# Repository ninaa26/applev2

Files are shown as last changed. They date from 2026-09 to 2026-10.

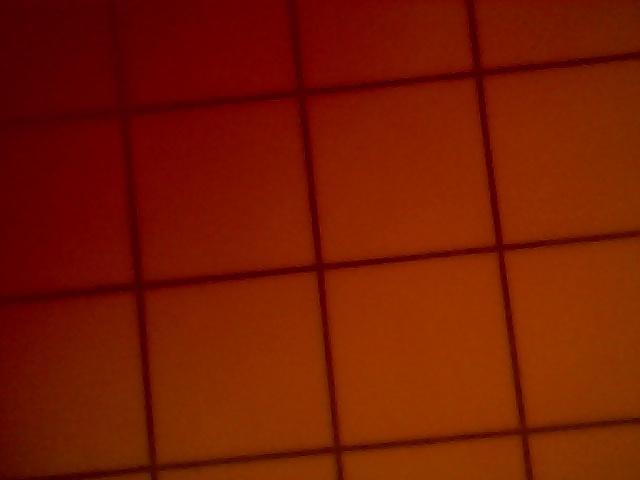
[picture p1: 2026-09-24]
server/tests/fixtures/empty_liner_webcam.jpg

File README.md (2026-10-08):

# Orchard Sentinel

A camera inside a pheromone delta trap that photographs its sticky liner, identifies and counts
codling moth, oriental fruit moth and obliquebanded leafroller, and turns the counts into the
biofix and degree-day timings from the NEWA guide. Cornell capstone, fall 2026.

Planning pages: [spec](https://claude.ai/artifact/GaBWYoqoXfmxyqFotrfH41) ·
[architecture](https://claude.ai/artifact/2WRtPNZk5ZcjBQNcR3oqus) ·
[build plan & tracker](https://claude.ai/artifact/VYyBzxuE8YnGAWV8XVyej5)

```
device/     Raspberry Pi 5 software: wake → LED → photo → queue → upload → set RTC alarm → power off;
            a Pi can also be the hub for ESP32 camera traps (device/esp32-node/ firmware)
server/     FastAPI + SQLite (Postgres later): upload API, detection/tracking/counting worker, dashboard
ml/         training photos (AMI, iNaturalist, trap-style synthetic), labelling tool, detector and classifier training and scoring
hardware/   trap dimensions (TRAP.md), mockup trap template, 3D-printable camera mount + liner tray, calibration prints
docs/       bring-up, wiring, running the server on the Mac, camera bench test, measuring accuracy
```

## Quick start (no hardware needed)

```bash
cd server && uv venv --python 3.12 .venv && uv pip install -p .venv/bin/python -e '.[dev]'
.venv/bin/sentinel-server init && .venv/bin/sentinel-server add-trap T1 --lure CM --name Bench
.venv/bin/sentinel-server serve          # http://localhost:8000
```

Then run the device software with the fake camera ([docs/server-on-mac.md](docs/server-on-mac.md#try-it-without-a-pi)).
With the Pi and camera: [docs/bring-up.md](docs/bring-up.md). More traps on ESP32 camera boards, sending through a hub Pi: [docs/esp32-traps.md](docs/esp32-traps.md). Choosing between cameras: [docs/camera-bench.md](docs/camera-bench.md).

## What works today

- Device cycle: capture with locked focus/exposure/white balance, SHT45 + INA219 readings, offline queue, upload, next-wake scheduling (DST-safe), RTC alarm + power-off, "new liner" by power-button wake; focus-sweep tool. Tested on a Mac with the fake camera. On a Pi so far: capture and white-card calibration with the wide-angle IMX219 on a bench Pi 5 ([hardware/CAMERAS.md](hardware/CAMERAS.md)); **the full cycle has not yet run on the Pi**.
- Server: authenticated uploads (duplicate-safe), new-liner handling, lure masking, detection (OpenCV baseline that measures the liner grid for scale and removes grid lines; corrects wide/fisheye lens distortion by straightening the grid, estimated once per liner; on empty-liner photos, re-run Oct 6 2026: 1 false box on a grid crossing in the Oct 1 webcam photo, and 7 on the IMX219 photo, all on the trap walls outside the card; ignores everything off the card when the lens also sees the trap's walls; leaves out a photo that is blurred or whose scale disagrees with its liner's other photos; folds part-boxes into one box per insect; logs sharpness, glare, liner age and moon with each photo; flatbug adapter; our YOLO11 on overlapping tiles as `SENTINEL_DETECTOR=yolo`), `sentinel-server detect` overlays for bench checks, tracking so each insect counts once (confirmed after 2 photos; species voted only from its first 72 hours on the glue), review queue with confirm/relabel/reject, BE degree days, NEWA sustained-catch biofix, pest milestones, dashboard pages.
- ML ([ml/README.md](ml/README.md)): training set from AMI and iNaturalist, trap-style synthetic photos and, since Oct 7 2026, 2,309 real insects cropped from liner photos (other people's OFM, CM and potato tuber moth liners, and our own field cards with species read from the photos, not yet checked by an entomologist); v1 classifier (BioCLIP 2 features + logistic regression, its settings and confidence scale tuned on real-liner crops): on liners and cards it never trained on it finds 94% of 162 OFM, 92% of 37 CM, 92% of 97 non-target moths, and on held-out field cards 18 of 19 OFM, 10 of 10 CM and 14 of 14 OBLR, at 7–15 px/mm; trained and scored from the `ml/` scripts but not yet switched on in the server (it runs with no species ID); three fine-tuned v2 CNNs (EfficientNet-B0, ConvNeXt-T, MobileNetV3-L; Oct 8 2026, on a CUDA PC) that match v1 on the 785 held-out real-liner crops overall (0.87–0.90 right against 0.89) but find only 3–6 of the 19 OFM on the held-out field card, against v1's 18, and are wrong at ≥ 0.80 3–5 times as often, so v1 stays the classifier; a YOLO11 detector (Oct 8 2026, 31 training photos, the same 4 test photos of other people's liners: mAP50 0.51, moth precision 0.79 and recall 0.74 at its chosen confidence, debris 0 of 13; no better than the Oct 7 run on half the photos), usable in the model playground and as a server detector, not yet tried on a target-size moth from our own camera; a browser labeller for field cards and liner photos; baseline and flatbug detectors scored on other people's labelled liner photos, the classifier scored on field-card crops as moth / other insect / debris.
- ESP32 camera traps ([docs/esp32-traps.md](docs/esp32-traps.md)): a hub Pi takes photos from ESP32-S3 camera boards in Wi-Fi range during each wake and uploads them under each camera's own trap, with each camera's own key. Cameras are added and removed on the dashboard (**Set up traps**), and the hub learns about them from the server. The firmware queues photos in flash, keeps its own time against the hub's and corrects for its clock drift. Tested in code and with a simulated camera through a real gateway on a Mac (Oct 8 2026). Not yet tested: the firmware on real Wi-Fi, and range in an orchard.
- Dashboard: an orchard view (traps reporting, this week's CM/OFM/OBLR across all traps, 30-day chart for the whole orchard) above the per-trap table; each trap's page and a page of all its photos.
- Review: the queue also shows one in ten labels the model was sure of (a spot check, scored on the trap page), and the trap page says when a biofix rests on catches nobody has confirmed.
- Automated tests for device, server and ml, run on every pull request ([.github/workflows/tests.yml](.github/workflows/tests.yml)), plus an end-to-end run: 6 fake-camera cycles → 3 moths detected, 2 confirmed, 1 candidate, which matches the fake camera's ground truth.

## Not done yet

ArUco alignment in the pipeline · white-card calibration for the LED's new position · a diffuser for the LED (10–13% of the card is blown out) · finishing the OFM liner labels (454 boxes) ·
accuracy on our own trap's photos, on locked test cards ([docs/evaluation.md](docs/evaluation.md)) · an entomologist's check of the field-card species and of the 454 pass-1 labels Claude added · a second source of OFM on glue (every CNN learnt the one trap camera's OFM) ·
dashboard settings page for `device_config` · alerts · Postgres/Docker for the real server.

What the insect-monitoring literature says works and fails, and what this repo does about each point, including what could not be done yet: [docs/cv-research-status.md](docs/cv-research-status.md) (imaging, detection, counting) and [docs/ml-research-status.md](docs/ml-research-status.md) (data, classification, evaluation).

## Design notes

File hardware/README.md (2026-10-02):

# Hardware files

The trap is the **Alpha Scents red plastic delta trap** with its 174 × 198 mm insert card (25 mm grid).
Measured dimensions, the schematic and what they mean for the camera: [TRAP.md](TRAP.md).

| File | What it is | Status |
|---|---|---|
| `TRAP.md`, `trap_schematic.svg` | Measured trap and card dimensions, end/side/top schematic | Measured |
| `mockup_template.py` → `mockup_template.svg` | 1:1 cut-and-fold template for a mockup delta trap (roof panels, floor, end flaps, cable slot, LED holes, liner + lure outline), plus a check that the camera sees the whole liner at your dimensions | Works; defaults are the measured Alpha Scents trap |
| `scad/camera_mount.scad` | Wedge that sits in the roof apex and holds the Camera Module 3 Wide facing down | Not yet rendered or printed. **Too low for this trap** (sees ~113 of the card's 174 mm across); needs to become a housing above the peak |
| `scad/liner_tray.scad` | Slide-in tray so every liner lands in the same spot, with pockets for the ArUco markers and a lure seat | Not yet rendered or printed. At the card's size it's wider than the 195 mm floor; shrink the rim/markers first |
| `make_markers.py` → `print/checkerboard.png`, `print/tray_markers.png` | Lens-calibration checkerboard and the four tray-corner ArUco markers (300 dpi) | Works; detection verified with OpenCV |

## Build the mockup

```bash
python mockup_template.py -o mockup_template.svg     # Alpha Scents defaults; --floor-width/--length/--flap/--apex/--liner for another trap
```

1. Print at **100 %** and check the 50 mm scale bar with a ruler.
2. Cut from corrugated plastic (the same material as a real delta trap) or foam board. Score the green dashed lines and fold.
3. Open the `.scad` files in OpenSCAD (free), set `floor_w`/`apex` (mount) and `liner_w`/`liner_l` (tray) to your numbers, press F6, and export STL.
4. Print the markers at 100 %, cut them out, and glue them into the tray pockets: id 0 top-left, 1 top-right, 2 bottom-right, 3 bottom-left, with the camera cable end at the top.
5. After changing the camera height, re-run `mockup_template.py` with the new `--cam-drop` to confirm the liner is still fully in view.

Wiring for the whole unit is in [../docs/wiring.md](../docs/wiring.md).

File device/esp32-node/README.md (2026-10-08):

# ESP32 camera trap firmware

An ESP32-S3 camera board in a delta trap that sends its photos through the hub Pi. How it fits
together, the Wi-Fi setup and adding cameras on the dashboard: [docs/esp32-traps.md](../../docs/esp32-traps.md).

Each wake it photographs the liner and saves the photo to flash. It joins the hub's Wi-Fi, uploads
everything queued (`POST /node/v1/captures`), and asks when to wake next (`GET /node/v1/schedule`).
Then it deep-sleeps. Pressing the button wired to `BUTTON_PIN` (the BOOT button by default) wakes it
and marks the photo as a fresh liner.

## Build and flash

PlatformIO (`pip install platformio`, or the VS Code extension):

```bash
cd device/esp32-node
cp include/node_config.example.h include/node_config.h   # then fill it in; it is gitignored
pio run -t upload
pio device monitor                                        # 115200 baud
```

The board this was written for: a Freenove-style ESP32-S3 CAM (N8R8: 8 MB flash, 8 MB octal PSRAM,
CH343 USB serial, ESP32-S3-EYE camera pins) with an OV3660. On a Mac the CH343 garbles uploads above
115200 baud, which is why `upload_speed` is 115200 (about 20 s per flash). Other boards need their
camera pins in `node_config.h` and maybe `board_build.arduino.memory_type` in `platformio.ini`.

`partitions.csv` keeps one 2 MB app slot and gives the rest of the flash (5.9 MB) to the photo queue.

## Serial output

What a normal wake looks like (format, not a recorded run):

```
sentinel node T2 fw 0.1.0 wake=scheduled boots=14 synced=1
captured /q/00000014-3f9a0c2e71b4d580 1600x1200 142311 bytes
wifi sentinel-hub ip 10.42.0.23 rssi -64
upload /q/00000014-3f9a0c2e71b4d580 -> 201
sleeping 12480 s
```

If the hub's Wi-Fi is up but its gateway is not open yet (`upload ... -> -1`), the node tries again every
5 s until the end of its connect window (2–5 min), then sleeps. `wifi ... failed status N mac ...`:
1 means the network was not seen, 4 that it refused the node (the password, or a network that wants
the MAC registered).

`ERROR camera not found`: the ribbon cable is loose or upside down, or the camera's pins differ from
`node_config.h`. `ERROR hub not reachable`: out of range, the wrong Wi-Fi password, or the hub was not
awake (it is awake for a few minutes after each scheduled time). `ERROR hub does not know this trap's
key`: the camera was removed on the dashboard, given a new key, or not added yet.

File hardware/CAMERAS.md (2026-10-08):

# Cameras

The camera looks down from the top middle of the trap, lens about 110 mm above the
174 × 198 mm card ([TRAP.md](TRAP.md)).

## Current trap camera: Arducam UC-572 (IMX219, wide-angle)

8 MP (3280 × 2464, 4:3), Raspberry Pi camera port (`imx219` driver), fisheye M12 lens, no focus
motor. From the peak of the trap it sees the whole card. Read off a preview of the card's 25 mm
grid: roughly 15 px/mm in the centre and 10–11 px/mm at the edges (not yet bench-tested).

- Focus by turning the lens by hand; `lens_position` is ignored.
- Optics, as far as they are known (2026-10-07). Measured: 15.3 px/mm at the card's centre with the
  lens ~110 mm above it, which with 1.12 µm pixels means an effective focal length of about 1.9 mm.
  A reseller's listing for Arducam's IMX219 wide-angle M12 module gives 2.5 mm, f/2.8, 155° × 115°;
  that would be 20 px/mm at 110 mm, so either the lens-to-card distance is nearer 145 mm or this board
  carries a different lens. Not settled: measure the distance and read the lens barrel. Depth of
  field, if it is f/2.8 and 1.9 mm, focused at 110 mm, allowing 2 px of blur: about 92–136 mm, so a
  flat card is inside it and a specimen standing 2 cm up on a pin still is.
- `lens_shading = false` and a white-card calibration (`sentinel-flatfield`) remove the green
  centre and pink edges the Pi's stock IMX219 colour correction gives with this lens.
- Light the card with the white LEDs and block daylight: through the red roof the photo is all red.
- Calibrated on the bench on 2026-10-06 (red trap, bench LED): `exposure_us = 40000`,
  `analogue_gain = 2.0`, `colour_gains = [0.89, 1.76]`; after `sentinel-flatfield` the card is
  an even neutral grey edge to edge. The LED leaves a blown-out glare patch on the card; diffuse
  it or aim it off the card. The saved correction (`flatfield.npz`) stays on the Pi it was made on.
- The Pi does not detect this board by itself (`camera_auto_detect=1` finds nothing). On the
  bench the driver was loaded by hand (`sudo dtoverlay imx219`), which is lost at reboot. For a
  trap Pi put `camera_auto_detect=0` and `dtoverlay=imx219` in `/boot/firmware/config.txt`
  (camera on the CAM/DISP 1 port).
- Detector on a calibrated photo of an empty liner (2026-10-06): grid 384 px = 15.3 px/mm, lens
  k −0.35. It reported 7 false insects, all on the trap walls and corner clips at the card's
  border. Since 2026-10-07 the detector ignores everything off the card and its outer 4 mm
  (baseline 0.4): 1 false box is left, on the card near its top-left corner. On uncorrected photos
  it misreads the grid, so the white-card correction matters for detection, not only for colour.
- Reference photos from that session (calibrated, uncorrected, stock tuning, exposure variants, one
  raw DNG) are in `ml/data/trap_camera/capture_2026-10-06/` on the Mac (not in git) and in
  `~/sentinel/capture_2026-10-06/` on the bench Pi.
- With seven pinned specimens on the liner (same day, `ml/data/trap_camera/capture_bugs_2026-10-06/`):
  wing patterns are visible even on a moth in the corner; the detector finds every specimen and
  ignores their shadows, but splits the large ones into several boxes, boxed the trap walls
  outside the card (gone with baseline 0.4: 31 boxes became 21), and estimates a different lens k
  (−0.10) than on the empty liner. Repeat photos of the same scene do not always read the same
  grid: `calibrated_3.jpg` of this set and of the next reads 40 and 34 px/mm instead of 14–16. The
  server now leaves out a photo whose scale is more than 20% from its liner's other photos. The single
  LED casts long red shadows; diffuse light from two sides would shorten them. The trap had been
  moved since the white-card calibration and the correction no longer lined up (faint green and
  pink patches): recalibrate whenever the camera or trap is moved.
- With the LED moved to shine down from beside the camera
  (`ml/data/trap_camera/capture_bugs_light2_2026-10-06/`): shadows are short and stay next to
  each specimen, which is the lighting to keep. It needs a diffuser (a blown-out hot spot right of
  centre, and the centre twice as bright as the edges) and a new white-card calibration: the light
  on the card is brighter and whiter, so start from `exposure_us = 40000`, `analogue_gain = 1.0`,
  `colour_gains` near `[1.28, 1.79]`. The values recorded above are for the old LED position.
- Steps: [docs/bring-up.md](../docs/bring-up.md), section 5.

## Also on hand

| Camera | What it is | In this trap |
|---|---|---|
| icspring USB camera | 640 × 480 UVC webcam | ~2.6 px/mm over the whole card (OFM ≈ 16 px). Software development only |
| Arducam UC-261 Rev D | 5 MP OV5647, Pi camera port, swappable M12 lens | Backup: ~10 px/mm with a ~1.7 mm lens for a 1/4" sensor |
| Pi camera in a clear acrylic holder | Normal-angle lens; sensor not identified yet (`rpicam-hello --list-cameras`) | Too narrow at the peak; worth identifying in case it is a 16 MP Arducam |
| Arducam UC-626 Rev B | 8 MP IMX219 USB, two microphones, fixed ~62° × 49° lens (looks scratched) | Too narrow at the peak |
| ArduCAM Mini UC-474 | 2 or 5 MP, SPI | No: not a camera-port device |
| OV7670/OV7725 board; OmniVision module on a UC-260 adapter | Parallel-pin microcontroller cameras | No |

## ESP32 trap camera: Freenove ESP32-S3-WROOM CAM + OV5640

An ESP32 build of the trap, for lower sleep power than the Pi. The board only takes, uploads and
schedules the photo; detection and species ID stay on the server, as with the Pi. The `device/`
package does not run on it: the capture and upload code has to be written as ESP32 firmware.

- Board: Freenove ESP32-S3-WROOM CAM (FNK0085). 24-pin DVP camera socket, `esp32-camera` driver.
  A 5 MP frame needs 8 MB PSRAM: check the module label reads N8R8 or N16R8. The team's other
  Freenove board ("v1.2", probably the original ESP32-WROVER) is not for the trap camera.
- **For now: the board's own OV3660** (3 MP, 2048 × 1536). Its stock lens is narrow (roughly 66°,
  not measured): from 110 mm it sees only about the middle 115 × 85 mm of the card, at roughly
  18 px/mm. Use it to bring up mounting, lighting, firmware and upload, not to count a whole card.
- **To replace it: an OV5640** (5 MP, 2592 × 1944, 1.4 µm pixels, on-chip JPEG), 24-pin 0.5 mm DVP,
  fixed focus, ordinary IR-cut lens (not 850 nm / night vision, not autofocus: the AF lenses see
  only ~70°). Buy two, the 130° and the 160°, from the
  [Taidacent listing](https://www.amazon.com/Taidacent-Degree-ESP32-CAM-OV5640-Camera/dp/B09NVRCFN1),
  choosing the longer ribbon:

  | Lens (diagonal) | Effective focal length | Whole card from 110 mm? | px/mm, centre / edges |
  |---|---|---|---|
  | **130°** (first choice) | ~2.0 mm | Yes, ~2 mm to spare per side; raise to ~115 mm if it clips | ~13 / ~8–11 |
  | 160° (backup) | ~1.6 mm | Yes, with room to spare | ~10 / ~7 |
  | 120° (not ordered) | ~2.2 mm | Probably clips 5–10 mm off the long edges | ~14 / ~9 |

  Estimated (2026-10-08) from the sensor size and the listed angles, assuming a fisheye
  (equidistant) lens with the sensor's long side along the card's 198 mm side; cheap listings round
  their angles, so none of this is measured. For comparison the UC-572 above (similar sensor size,
  ~1.9 mm) sees the whole card at 15.3 px/mm. Either OV5640 lens is below the 15 px/mm target:
  enough to count, but OFM against look-alikes at the edges may suffer.
- When the OV5640s arrive: compare each ribbon's pin order with the OV3660's before plugging in,
  focus the lens to 11 cm by turning it out and glue it, then take one full-resolution photo of
  the grid card per lens and check all four corners are in frame and read px/mm off the 25 mm grid.
  Keep the 130° if it covers the card.
- The camera's JPEG output and its limited exposure and colour control mean the white-card
  correction would be applied on the server, to JPEGs.

## What a trap camera needs

| | Need |
|---|---|
| Field of view | ≥ 80° on the sensor's short side, ≥ 87° on the long side (lens at 110 mm) |
| Detail | ≥ 15 px/mm on the card, corners included (OFM ≈ 90 px); ≥ 20 px/mm for look-alikes |
| Sensor | ≥ 12 MP, 4:3, normal IR-cut (not NoIR), Pi 5 CSI/libcamera support |
| Lens and focus | Low distortion, rated for the sensor; sharp at 10–11 cm and locked |

## Upgrade if the edges or look-alikes need more: Raspberry Pi HQ Camera (M12) + Arducam LN069 lens

- Camera: Raspberry Pi HQ Camera, **M12-mount** version (SC0870, IMX477, 12.3 MP, 4:3), ~$50 at
  [PiShop.us](https://www.pishop.us/product/raspberry-pi-hq-camera-m12/) or
  [CanaKit](https://www.canakit.com/raspberry-pi-hq-camera-m12.html). No lens included.
- Lens: [Arducam LN069](https://www.arducam.com/arducam-100-degree-low-distortion-1-2-3-inch-m12-lens-with-lens-adapter-for-raspberry-pi-high-quality-camera-ln069.html)
  (M23270H10): 2.7 mm f/2.8, 100° × 83°, distortion < 1.5 %. From 110 mm it sees ~262 × 195 mm,
  the whole card, at ~15.5 px/mm (OFM ≈ 93 px). Rated minimum focus is 0.3 m: check it focuses at
  11 cm (screw the lens out further, or add a spacer) as soon as it arrives.
- Also: a Pi 5 camera cable (22-pin to 15-pin) long enough to reach from the peak to the Pi.
- Software: nothing to add; `camera.py` handles fixed-focus cameras. Manual focus, so set it once
  and lock the lens, then redo `sentinel-flatfield`.

## Ruled out

| Camera | Why not |
|---|---|
| Camera Module 3 Wide | Works, with autofocus and existing code, but needs the lens 131–150 mm up (a housing above the peak) for ~13–15 px/mm. The fallback |
| Raspberry Pi AI Camera (IMX500) | Fixed 66° × 52° lens: needs the lens ~177 mm up. Its on-sensor models see a downscaled frame (~3–4 px/mm over the card), too coarse for species; detection runs on the server anyway |
| Arducam 64 MP Hawkeye | Needs ~160 mm; big photos and battery cost for detail the counting problems don't need |
| Ordinary USB webcams | Fixed focus far from 11 cm, exposure/white balance that can't be locked, heavy compression, narrow lenses, USB drop-outs |
| [Arducam 12 MP IMX477P USB 3.0](https://www.arducam.com/arducam-12mp-imx477p-usb-3-0-camera-with-m12-manual-focus-lens-without-enclosure.html) | Not ruled out: same sensor, takes the same lens, works on a Mac with the existing USB backend. Costs more, ~1.3 W, compressed frames, less control. The pick if we want USB |
| Two cameras (Pi 5 has two ports) | Trapview covers its card with 4 × 5 MP cameras. Only if the HQ Camera's corners are too soft |

## From the literature

Suto 2022, *Codling moth monitoring with camera-equipped automated traps: a review*
(Agriculture 12:1721): traps used 2–10 MP cameras (Trapview 4 × 5 MP, iSCOUT 10 MP, Pi Camera v2
8 MP). Counting codling moth worked at 640 × 480 (93.1 AP, Ding & Taylor 2016), so resolution
wasn't the limit; touching insects, look-alike moths, torn wings and too little training data were.
Those papers only separated codling moth from background, not three species, so our 15 px/mm target
stands. One photo a day is enough, and ~20 % count error is tolerable for forecasting.

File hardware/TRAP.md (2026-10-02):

# The trap: Alpha Scents plastic delta trap (red)

We use the [Alpha Scents plastic delta trap, red](https://alphascents.com/products/plastic-delta-trap-red-complete-includes-sticky-insert-and-hanger)
(corrugated plastic, sold with a sticky insert and hanger) with the
[Alpha Scents plastic delta insert card](https://alphascents.com/products/plastic-delta-trap-sticky-insert).
Alpha Scents doesn't publish the trap's size; everything below was measured with a ruler on a real
trap and card.

Trap schematic

## Trap

| What | mm |
|---|---|
| Roof panels (each side of the triangle) | 150 |
| Floor width (bottom of the triangle) | 195 |
| Floor to inside roof peak | 110 |
| Length, end flaps folded up (open end to open end) | 227 |
| Length laid flat (flaps unfolded) | 278 |
| End flaps, one at each opening | 25.5 = (278 − 227) / 2 |

The end flaps sit on the short sides of the floor rectangle, at the two triangular openings. When the
trap is assembled they fold up, and the sticky card sits on the floor between them.

150 mm panels over a 195 mm floor work out to a 114 mm peak; the measured 110 mm is what the
camera numbers use.

## Sticky card

| What | mm |
|---|---|
| Card | 174 across the trap × 198 along it |
| Printed header ("Plastic Delta Insert Card") at one end | 174 × 22 |
| Grid | 7 × 7 squares, **25 mm** (not 1 in): `SENTINEL_GRID_MM=25` |

Centred on the floor, the card leaves about 10.5 mm of floor on each side and 14.5 mm at each end.

## What this means for the camera

The peak is low. With the Camera Module 3 Wide (102° × 67°) the view across the trap is the tight
direction, and covering the card's 174 mm needs the lens about **131 mm** above it (150 mm for some
margin), which is 21–40 mm *above* the roof peak. From inside, the camera misses the card's edges:

| Lens above the card | View along × across (mm) | Whole card? |
|---|---|---|
| 85 mm (mount 25 mm below the peak) | 210 × 113 | no |
| 110 mm (lens at the peak) | 272 × 146 | no, ~14 mm missed on each side |
| 150 mm (roof housing, 40 mm above the peak) | 370 × 199 | yes, ~13 px/mm |

Check any layout with `python mockup_template.py --cam-drop <mm>` (a negative drop puts the lens
above the peak). The slide-in tray in `scad/liner_tray.scad` (markers in an 18 mm rim) is wider than
this floor and needs a redesign before printing.

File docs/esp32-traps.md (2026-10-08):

# ESP32 camera traps through a hub Pi

One Raspberry Pi in the orchard is the **hub**. More traps, each with an ESP32-S3 camera board instead
of a Pi, hang in Wi-Fi range of it. Every wake they photograph their liner, send the photo to the hub,
and deep-sleep. The hub uploads their photos to the server with its own.

```
ESP32 trap T2 ─┐  Wi-Fi (hub's access point)                 Tailscale
ESP32 trap T3 ─┼──────────────────────────► hub Pi T1 ───────────────────► server (Mac)
ESP32 trap T4 ─┘  POST photo, GET schedule   gateway.py: queue per trap,   /api/v1/captures,
                                             upload with each trap's key   /api/v1/hub/nodes
```

- **Server:** each ESP32 is a trap of its own, with its own key, page, liner, photos and counts. It is
  marked as an ESP32 camera and names its hub. Cameras are added and removed on the dashboard's
  **Set up traps** page (or `sentinel-server add-trap T2 --lure CM --kind esp32 --hub T1`). Removing
  one hides it and stops its key, and keeps its photos and counts. **Put back** undoes it.
- **Hub:** `sentinel_device/gateway.py`. Each wake it asks the server which ESP32 traps are its own
  (`GET /api/v1/hub/nodes`: their ids and key hashes, cached for wakes without a connection), so the
  hub needs no change when cameras are added or removed. The cycle opens the gateway while it
  photographs its own liner, and keeps it open for `[hub] window_s` (240 s), or less once every node
  has checked in. Then it uploads its own queue and every node's queue (`data_dir/nodes/<trap_id>/`)
  with each node's key, and powers off as before.
- **ESP32 trap:** `device/esp32-node/` (PlatformIO). Each wake it takes a photo and saves it to flash,
  joins the hub's Wi-Fi, and uploads everything queued, oldest first. It asks the hub when to wake
  next, then deep-sleeps. A photo stays on the ESP32 until the hub has it, so a missed window costs
  nothing but delay. The queue has 5.9 MB of flash, room for roughly 40–60 UXGA photos; when it is full the oldest go first.

Which camera module to put on the ESP32 (OV3660 for bring-up, OV5640 wide-angle to buy):
[hardware/CAMERAS.md](../hardware/CAMERAS.md).

## Timing

The hub wakes on its schedule (`[schedule] times`). Nodes aim for `node_offset_s` (60 s) after each
slot, when the hub has booted and its access point is up. Each reply from the hub carries the time and
the next 12 wake times, so a node that misses the hub once still wakes for the next slot.

The ESP32's sleep clock is an RC oscillator that can be off by a few percent. The node never sets its
clock. It measures the hub's time against its own on every contact, works out its drift from
successive contacts, and corrects the next sleep. It also wakes early by `15 s + 0.3%` of the sleep
(about 2.5 min before a 12 h slot) and keeps trying the hub's Wi-Fi for 2–5 min. A node that has
never reached the hub tries every 10 min, so run the hub's gateway standalone while installing nodes
(below).

What this costs the hub: each wake it stays on up to `window_s` longer, 4 min by default against about
1.5 min without nodes. The systemd unit allows the cycle 600 s.

## Wi-Fi between the hub and the traps

The hub's onboard Wi-Fi already connects it to the internet (orchard Wi-Fi or a phone hotspot), and one
radio can't reliably be a client and an access point at once. Choose one:

- **USB Wi-Fi adapter on the hub as the access point (recommended).** It needs one whose chipset
  supports AP mode on Linux (`iw list` shows `AP` under "Supported interface modes"). Choose one with
  a screw-on antenna: a bigger antenna on the hub also extends range to the traps. `wlan0` stays the
  uplink.
- **Onboard Wi-Fi as the access point**, if the hub reaches the internet some other way (Ethernet, or
  a USB LTE modem).

Access point with NetworkManager (Pi OS Bookworm). `ipv4.method shared` gives the hub 10.42.0.1 and
hands out addresses to the traps:

```bash
sudo nmcli con add type wifi ifname wlan1 con-name sentinel-hub autoconnect yes ssid sentinel-hub \
  mode ap 802-11-wireless.band bg 802-11-wireless.channel 6 ipv4.method shared \
  wifi-sec.key-mgmt wpa-psk wifi-sec.psk 'choose-a-password'
sudo nmcli con up sentinel-hub
```

**Range is not measured yet.** Expect less than in open air: 2.4 GHz through leafy apple canopy loses
a lot. Every photo's metadata carries the node's signal strength (`device.rssi`). Before hanging a
trap, take its board to the spot and check that the hub hears it at better than about -80 dBm. For
traps further out, ESP32-S3 boards with an antenna connector (WROOM-1U modules) and an external
antenna are the next step.

## Adding and removing ESP32 traps

Once, on the hub: `[hub] enabled = true` in `/etc/sentinel/config.toml`, and its access point (above).

For each camera:

1. Dashboard → **Set up traps** → Add a camera: ESP32 camera, its hub, trap id, name, block and lure.
   The page shows the camera's key **once**, as the two lines for `node_config.h`.
2. Firmware: `cd device/esp32-node && cp include/node_config.example.h include/node_config.h`. Paste
   those two lines, fill in the hub's Wi-Fi name and password and the LED pin, and flash it:
   `pio run -t upload` ([esp32-node/README.md](../device/esp32-node/README.md)).
3. Hang it and power it. The hub accepts it from its next wake. To see the first photo straight away,
   run `sentinel-gateway --config /etc/sentinel/config.toml --forward-every 60` on the hub (it refreshes
   the camera list every minute), or do the first contact on the bench.

To take a camera out, press **Remove** on the same page. The hub stops taking its photos from its next
wake. Photos already queued on the hub still go up, and the server keeps all of them. A lost or
reflashed board can get a **New key**.

Cameras can also be listed by hand in the hub's config (`[hub.nodes.T2] api_key = "..."`), for a
bench hub that has no server to ask.

## Bench test without the orchard

**Hub Pi and ESP32 on the same Wi-Fi (done Oct 8 2026 on RedRover).** No access point is needed if the
Pi and the ESP32 join one network that lets devices reach each other. Cornell's RedRover does: it took
the ESP32 without registering its MAC, and routes between its /16s (the Pi was on 10.49.x, the Mac on
10.50.x). In `node_config.h` set `WIFI_SSID "RedRover"`, `WIFI_PASSWORD ""` and `HUB_URL` to the
Pi's address on that network (`ip -4 -br addr` on the Pi). That address comes from DHCP and can change,
so check it before a test. On the Pi, run the gateway from its own folder with a bench config
(`trap_id`, `api_key`, `server_url`, a writable `data_dir`, `[hub] enabled = true`):
`sentinel-gateway --config bench-hub.toml --forward-every 20`. The server can be a Mac on Tailscale.

**Hub on a Mac.** The gateway runs on a Mac too. Put the Mac and the ESP32 on the same Wi-Fi, set `HUB_URL` to
`http://<mac's address>:8080`, and give the Mac a config with `data_dir` somewhere writable,
`server_url = "http://localhost:8000"`, the hub trap's `trap_id` and `api_key`, and `[hub] enabled = true`,
then run `sentinel-gateway --config that.toml --forward-every 30` beside `sentinel-server serve`.

## Status (Oct 8 2026)

- Bench run on real Wi-Fi (Oct 8 2026): the ESP32-S3 (OV3660) on RedRover at -52 dBm, the gateway on
  the bench Pi (sentinel-t1), and a scratch `sentinel-server` on the Mac over Tailscale. Five photos
  queued on the ESP32 from earlier failed tries went up oldest first, the Pi forwarded them with
  T2's key, and they were on the server within a second. The node got its schedule and slept until
  the next slot plus `node_offset_s`.
- Built and tested: the gateway and the hub cycle (`device/tests/test_gateway.py`), adding and removing
  cameras on the dashboard (`server/tests/test_manage.py`), and on this Mac: a camera added on the
  dashboard, picked up by a real `sentinel-gateway`, a photo posted the way the firmware does with its
  key, and on its trap page seconds later. The node firmware compiles. The camera check found the board's pins (ESP32-S3-EYE / Freenove layout) and an OV3660,
  and took 1600×1200 photos over USB.
- Not yet done: the node on the hub's own access point, drift correction over real sleeps, range in the
  orchard, and the ESP32's deep-sleep current (dev boards have a power LED and USB chip that draw
  power even while the ESP32 sleeps).
- ESP32 photos get no white-card correction (`flatfield.npz` is done on the Pi), so they reach the
  server uncorrected. Exposure is auto unless `CAM_AEC_VALUE`/`CAM_AGC_GAIN` are set. Calibrate per
  trap as for a Pi.

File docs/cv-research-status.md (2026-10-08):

# Insect-CV research: what we did with each finding

Status of every item in "Moth Monitoring: Computer Vision (Imaging, Detection, Counting)" (Oct 6 2026)
against this repo, as of Oct 8 2026. Start with what could **not** be done; the full item-by-item list follows.

Words used: **Done** = changed in code or docs on Oct 6–7 2026 and tested. **Had** = already how the repo
worked. **Not ours** = about light traps, other hardware or other pests. **Open** = see the first two sections.

## Could not be done here

| # | Item | Why not | What would settle it |
|---|---|---|---|
| 1 | A detector score on our own trap | No moth of target size has been photographed by the trap camera; `ml/data/own/` does not exist | Stage cards in the trap, lock test cards, run `sentinel-server evaluate` ([evaluation.md](evaluation.md)) |
| 2 | Retrained YOLO with the new options scored on its test photos | Partly done: two runs with the three-way split, overlap 224 and blank liners, same 4 test photos (`ml/README.md`). Oct 7, 16 training photos: test mAP50 0.52, moth precision 0.77 and recall 0.80 at the chosen settings. Oct 8, 31 training photos (OFM liners fully labelled, CUDA PC): test mAP50 0.51, moth 0.79 and 0.74. Twice the labels, no visible gain; debris found in neither. `--imgsz 800`, `--one-insect-class` and `--synth` have not been compared | One run per option, same test photos; more test photos to tell runs apart |
| 3 | Trap-style training photos on trap-camera liners | The only blank IMX219 liner photos predate the LED move; the camera needs its white-card calibration redone first | Recalibrate, photograph a blank liner, put it in `ml/data/liners/`, re-run `make_trap_style.py` |
| 4 | Glare removed at the source | Hardware: the LED needs a diffuser or re-aiming. Measured Oct 6 photos with the LED beside the camera: 10–13% of the card blown out to white. Software now measures it and raises a `glare` event, nothing more | Diffuser, then recalibrate |
| 5 | Lens focal length and aperture confirmed | Our measurement (15.3 px/mm at ~110 mm) implies ~1.9 mm; a reseller's listing says 2.5 mm f/2.8. Unresolved ([CAMERAS.md](../hardware/CAMERAS.md)) | Measure lens-to-card distance, read the lens barrel |
| 6 | Counting crowded liners with the YOLO detector | The baseline estimates touching clumps by area; YOLO has nothing equivalent, and we have no crowded liner with a true count to build or check one | A labelled liner past ~60 insects |
| 7 | Telling a spread-wing moth from two touching moths | Part-boxes are now folded into the whole insect, but a single blob of two wings still goes to review as "2?". No spread-wing example with a true label exists in our data | Stage spread-wing moths on a locked card |
| 8 | Insects under 3 mm | The baseline ignores them on purpose (targets are 6 mm and up; smaller boxes are mostly dust). Their counts are therefore not reported. YOLO labels do include them | Nothing, unless bycatch counts become a goal |
| 9 | Hard-negative bootstrapping from our own false alarms | Needs reviewed photos from our trap (rejected detections). Blank liners are in as negatives; the loop itself is not built | Dashboard reviews, then extend `export_server_crops.py` to write YOLO backgrounds |
| 10 | Wind, and hourly weather, logged per photo | No sensor and no feed for them; temperature, humidity, battery, liner age and moon are logged | A weather feed (NEWA) joined by time |
| 11 | Pi-side numbers: energy per photo, battery days, memory on the Pi | The full cycle has not run on a Pi yet; detection runs on the Mac, where it was measured (4–5 s, 350 MB) | Bench cycle on the trap Pi with the INA219 log |
| 12 | Seals, battery storage, lure placement, liner changes | Physical. Written as a checklist: [bring-up.md](bring-up.md), "Before a trap goes out" | Doing the checklist |
| 13 | Liner discolouring over a season, and a different liner or trap colour | No season of photos yet. The card's colour is now logged with every photo so drift can be seen; any change of liner, colour, light or camera needs new locked cards | A season of photos |
| 14 | Measuring tracking on real sequences | The score exists (`insect` column in `boxes.csv`) and is unit-tested; no real multi-day sequence has been labelled | Box one liner on 3+ days |

## Needs your decision

- **Photos per day.** One a day is enough for pheromone traps and saves most battery (Suto 2022). The trap takes
  six. Two-photo confirmation needs a second photo, so at one a day a catch is confirmed a day late (it is still
  dated to the day it was first seen). A middle way that keeps same-night confirmation: 22:00 and 07:00. Not
  changed: it trades battery against delay, and battery life has not been measured.
- **Liner age limit.** `SENTINEL_LINER_MAX_DAYS=28` is our own number, not from the research.
- **Shape filter on the baseline** (from our own Oct 2 test, not this research): still not ported.

## What worked

| Finding | Status | What we do |
|---|---|---|
| Slicing / tiled inference | Done | Server YOLO detector runs on overlapping tiles at the trained px/mm; tiles merged by overlap with the smaller box. Baseline shrinks to 1,600 px: full size was tested and gained 1 moth of 211 for 2.4× the time, so it stays |
| Two-stage detect → classify | Had | Detector finds everything, classifier names it. The classifier is still switched off in the running server |
| Tuning NMS and max detections | Done | Max detections 1,000 per tile. NMS IoU and confidence are chosen on val by F1 and saved with the run. Yolo-pest's IoU 0.9 was tried: moth F1 0.74 against 0.84 at 0.5, so not copied |
| Larger, screened dataset; higher input size | Done / Open 2 | `--imgsz` added. Dataset: 25 fully labelled photos; 17 OFM liner photos still to label |
| Generic insect detector | Done | Server drops YOLO's classes and sends every box to the classifier; `--one-insect-class` trains it that way. Not yet compared |
| Synthetic copy-paste data | Had / Open 3 | `--synth` pastes cut-out web insects; `--blank` tiles are now among its backgrounds. Its one run was stopped at epoch 7 |
| Hard negatives; rotation / translation | Done / Open 9 | Blank trap-camera liners as empty tiles. Rotation, flips and scale were already in training |
| Grey-world colour correction | Had | Fixed colour gains plus white-card flat field do more than grey-world. Card colour now logged per photo to catch drift |
| Lightweight backbone | Not ours | Detection runs on the Mac. `--model yolo11n.pt` exists if it ever moves to the Pi |
| Tracking with appearance embeddings | Not ours | Insects on glue don't move; position matching is enough |
| Minimum track length | Had | Confirmed on the second photo; single sightings are dropped |
| 2-min time-lapse | Not ours | Light traps |
| On-device detect on a low-res stream | Not ours | Server-side |
| Image-based MCU trigger | Not ours | Scheduled wakes by RTC |
| Density / regression counting | Had / Open 6 | Baseline counts clumps by area and sends them to review; `card_full` at 60 |
| Self-cleaning trap | Not ours | No mechanism; liner changes instead (`card_full`, `card_old`) |
| Controlled light, background, distance | Had / Open 4 | Fixed exposure, gains and white-card map per camera and light |
| Edge hardware choice | Not ours | Pi 5 captures only |

## What didn't work

| Pitfall | Status | How we avoid it |
|---|---|---|
| Blob / background-subtraction detection | Done / Open 1 | Ours is still the default until a YOLO run is scored on our liners; YOLO is now selectable. Its known failures are guarded: off-card boxes, part-boxes, mis-scaled and blurred photos |
| SAM as the detector | Had | Never used; cut-outs come from flatbug |
| Full-image inference on high-res images | Done | Tiles (above) |
| Upgrading detector version as the fix | Done | Rule in `.claude/rules/ml.md`: labels and resolution first |
| Leaving small insects out of labels | Done / Open 8 | Labelling rule added; public sets where only the target was boxed are kept out of training |
| Box detectors on dense, overlapping catches | Open 6 | |
| PIR / heat triggers; IR beam counters | Not ours | |
| Double detections on large moths | Done / Open 7 | `merge_fragments`: 31 → 25 and 21 → 17 boxes for 7 pinned specimens; 2 of 328 OFM lost |
| Tracking fast or similar insects | Not ours | Stationary insects |
| Lab-only or single-background training | Done / Open 3 | Blank trap-camera liners added; trap-style classifier data still on 3 webcam liners |
| Tiny trigger CNNs | Not ours | |
| Slicing on a Raspberry Pi | Not ours | Slicing runs on the Mac: 10–12 s a photo |

## Overlooked considerations

| Item | Status | What we do |
|---|---|---|
| Document the optics | Done / Open 5 | Derived focal length, depth of field and the disagreement with the listing are in CAMERAS.md |
| Resolution sets the taxonomic ceiling | Done | `evaluate` reports px/mm and the OFM's length in px against the 50 px minimum |
| Report results by object size | Done | Recall and species accuracy in four size bins |
| Glare and landing surface | Done / Open 4 | Glare measured per photo, `glare` event over 2% |
| Unusable frames | Done | Blurred or mis-scaled photos are left out and counted in the report |
| Decay after ~72 h | Done | Species vote only from a moth's first 72 hours; confirmed moths stay counted when later missed |
| Non-insect objects | Done | Off-card boxes dropped; lure mask; `debris` class; false moths reported by cause |
| Background colour, discolouring | Open 13 | Card colour logged per photo |
| Spread wings | Done / Open 7 | |
| Pick and validate a counting rule | Had | New arrivals by tracking; validated by `evaluate` per liner and per trap-day |
| Light-off recounts; rare taxa; different community | Not ours | |
| Tracking is rarely measured | Done / Open 14 | |
| Busy nights spike memory | Done / Open 11 | Mac: 350 MB peak for the baseline on an 8 MP photo |
| Field failures are mundane | Open 12 | Checklist |
| Storage | Done | 2.2 MB a photo, ~2.4 GB per trap per season; server keeps all, trap keeps its last 200 |
| Log context with each image | Done / Open 10 | Liner age, moon, sharpness, glare, card colour, px/mm, temperature, humidity, battery |

## Things not to do

| # | Don't | Status |
|---|---|---|
| 1 | Downscale a high-res image into a detector | Done: tiles for YOLO; baseline tested at full size |
| 2 | Leave small, blurry or partial insects out of labels | Done: labelling rule; overlap fits the longest moth so each is whole in some tile |
| 3 | Blob detection or SAM in production | Open 1: baseline stays only until YOLO is scored |
| 4 | PIR or IR beams | Not ours |
| 5 | Sum detections across frames | Had: tracks |
| 6 | Let sticky surfaces fill up | Done: `card_full` at 60, `card_old` at 28 days |
| 7 | Lure in view; scale shedding | Had (mask) / Open 12 |
| 8 | Change the setup without re-validating | Done: stated in evaluation.md; scale check catches a moved camera |
| 9 | Chase newer YOLO versions | Done: rule |
| 10 | Assume a box detector counts crowds | Open 6 |
| 11 | Report only mAP | Done: count error per liner and per trap-day, by size, by cause; rule |
| 12 | Skip pre-deployment hardware tests | Open 12: checklist |
| 13 | Throw away raw images | Had: server keeps every photo |

## Pheromone / sticky traps

| Item | Status |
|---|---|
| One image per day | Needs your decision |
| Count new arrivals; track across days so a decaying moth isn't new | Had |
| Detector classes for debris | Had: YOLO `debris`, classifier `debris`; scored 0.04 with 89 boxes, so more debris labels are needed (Open 2) |
| Slice and raise max detections; density counting for overlap | Done / Open 6 |
| Varied phones | Not ours: growers don't photograph these traps |
| ±20% count error; trend alerts first | Had: pass mark 0.80; alerts are not built |

## Light traps / screens

All four items (time-lapse interval, appearance tracking with re-entries, intermittent lighting, solar sizing):
not ours.

## CV pipeline checklist

| Step | Status |
|---|---|
| Fix the hardware and document optics | Open 4, 5 |
| px/mm from the smallest target | Done: reported by `evaluate`; bring-up check |
| Capture schedule; no PIR | Needs your decision |
| Log liner age, moon, weather | Done / Open 10 |
| Label every insect plus debris | Done (rule); 454 boxes still unlabelled |
| Augmentation, hard negatives, synthetic copy-paste | Done / Open 2, 9 |
| Sliced inference; tuned NMS and max detections | Done |
| Counting method | Had |
| Label sequences to measure tracking and counting | Open 14 |
| Count error per trap-day, by size, by false-positive cause | Done |
| Benchmark latency, memory, energy | Done on the Mac / Open 11 |
| Crops to the classifier; archive raw images | Had |

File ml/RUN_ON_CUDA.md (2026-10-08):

# Training on a machine with a CUDA GPU

The bundle from `make_bundle.py` (`orchard-train.zip`, 1.75 GB) holds the scripts, the dataset and every image
it lists. Nothing else is needed from the Mac, and nothing here needs Claude: these are ordinary Python
scripts. Written for an RTX 3060 Ti (8 GB) under WSL 2 on Windows; plain Linux is the same minus the WSL notes.
Allow about 10 GB of free disk and 2–3 hours for everything (estimates, not measured on that card).

## Before you start (WSL)

- **WSL 2, not WSL 1.** In PowerShell: `wsl -l -v`.
- **NVIDIA driver on Windows only.** Install the normal Windows driver; do not install an NVIDIA driver inside
  WSL. `nvidia-smi` inside WSL should then show the 3060 Ti.
- **Keep the files inside WSL.** Unzip into your Linux home (`~`), not under `/mnt/c/...`: reading 41,000
  photos from the Windows drive is several times slower.
- **Internet for the first run:** PyTorch, the packages, and each network's pretrained starting weights.

## Set up (once)

```bash
sudo apt update && sudo apt install -y zip unzip python3-venv
cp /mnt/c/Users/YOU/Downloads/orchard-train.zip ~/ && cd ~        # YOU = your Windows user name
unzip -q orchard-train.zip && cd orchard-train/ml
python3 -m venv .venv && . .venv/bin/activate
pip install torch torchvision --index-url https://download.pytorch.org/whl/cu124
pip install -r requirements-train.txt
python -c "import torch; print(torch.cuda.is_available(), torch.cuda.get_device_name(0))"   # must print True
```

If the last line prints `False`, the GPU is not visible in WSL: check `nvidia-smi`. Every command below runs
from `~/orchard-train/ml` with the environment active (`. .venv/bin/activate` in a new terminal).

## 1. Species classifier, fine-tuned CNN (v2)

Three runs, each a different size of network. Each prints its time after every epoch, so one epoch × 20 is
the run's length: very roughly 15–30 min, 25–45 min and 10–25 min.

```bash
python train_v2.py --arch efficientnet_b0    --epochs 20 --batch 64 --samples-per-epoch 24000 --out models/v2
python train_v2.py --arch convnext_tiny      --epochs 20 --batch 32 --samples-per-epoch 24000 --lr 1e-4 --out models/v2-convnext
python train_v2.py --arch mobilenet_v3_large --epochs 20 --batch 64 --samples-per-epoch 24000 --out models/v2-mobilenet
```

If one result tonight is enough, run the first.

- **"CUDA out of memory":** halve that run's `--batch` and run it again.
- **Killed with no error message:** WSL ran out of RAM (it gets about half the PC's by default). Add `--workers 4`,
  or `--workers 2`.
- **Slow epochs with the GPU mostly idle** (`nvidia-smi` in a second terminal): the photos are the bottleneck.
  Check the files are not under `/mnt/c`, and add `--workers 8` if the PC has 8 or more cores.

Each run writes `<arch>.pt`, `metrics.json` and `report.md` into its folder. **The table to read is
"test · real liners (held out)"** in `report.md`: recall for CM, OFM, OBLR and other_moth on moths that sat on
glue and that no model trained on. The web-photo and trap-style tables only show the pipeline works.

## 2. Species classifier, linear head on BioCLIP 2 (v1)

Already trained on the Mac (`models/v1/`; its `report.md` is the bar v2 has to beat). Optional: retraining it
here takes a few minutes with the cached features in `data/embeddings/`, plus a model download of a GB or
more the first time.

```bash
python train_v1.py --device cuda --batch 64
python eval_liner_species.py --device cuda        # what the server would do with each held-out crop
```

## 3. Detector (YOLO11)

Uses the fully labelled photos only: 11 field cards and all 31 OFM liner photos (17 of them finished on
Oct 7 2026), plus blank trap-camera liners as empty tiles. Perhaps 30–60 minutes; it stops early when val
stops improving, so it can be left overnight. Batch 16 for 8 GB; drop to 8 if it runs out of memory.

```bash
python train_yolo.py --device 0 --batch 16 --out data/yolo-cuda --name yolo11s-ppm12-cuda \
    --blank 'data/trap_camera/capture_2026-10-06/calibrated_*.jpg' --blank-ppm 15.3
```

Read the `test` block of `models/yolo11/yolo11s-ppm12-cuda/summary.json`; the `val` block picked the
checkpoint and flatters it.

## Bring back

Zip the results and copy the zip to Windows, then to the Mac:

```bash
cd ~/orchard-train/ml && zip -qr results.zip models -x 'models/v1/*' && cp results.zip /mnt/c/Users/YOU/Downloads/
```

On the Mac, unzip it inside `ml/` so the folders land under `ml/models/`:

- `models/v2/`, `models/v2-convnext/`, `models/v2-mobilenet/`
- `models/yolo11/yolo11s-ppm12-cuda/` (`weights/best.pt` and `summary.json` are what matter)

Then in `server/.env`: `SENTINEL_CLASSIFIER=cnn-v2` with `SENTINEL_CLASSIFIER_MODEL=../ml/models/v2/<arch>.pt`,
or `bioclip-v1` with `SENTINEL_CLASSIFIER_HEAD=../ml/models/v1/head.npz`, whichever scored better on the real
liners.

Done once, Oct 8 2026, on an RTX 3060 Ti: v1 scored better (the CNNs miss most OFM from a second camera), so
the server stays on `bioclip-v1`. The numbers are in [README.md](README.md), "The CUDA runs".

## What the labels are worth

The species on real liners comes from three places: the uploader of each public set, pass-1 labels on the
OFM liners (454 of them by Claude on Oct 7 2026, listed in `labelled_by_claude.csv`), and species on the
field-card moths read from the photos by Claude (`data/field/species.csv`, not yet checked by anyone who
knows the moths). Treat every score as provisional until those are checked.

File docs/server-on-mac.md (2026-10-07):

# Running the server on the team Mac

The Mac runs the API, the dashboard, and the worker that detects and counts insects, all in one process.
Moving to a real server later means copying the `data/` folder and running the same commands there.

## Setup (once)

```bash
brew install uv                       # if needed
cd server
uv venv --python 3.12 .venv
uv pip install -p .venv/bin/python -e '.[dev]'
cp .env.example .env                  # edit if needed
.venv/bin/sentinel-server init
.venv/bin/sentinel-server add-trap T1 --lure CM --name "Bench mockup"   # prints the trap's API key
```

## Run

```bash
caffeinate -s .venv/bin/sentinel-server serve     # caffeinate keeps the Mac awake while plugged in
```

Dashboard: http://localhost:8000 on the Mac, or `http://<mac's tailscale name>:8000` from teammates' laptops and the Pi.

**Who can open it.** The server listens on every network the Mac is on, not only Tailscale, so without a password
anyone on the same Wi-Fi can open the dashboard, submit reviews and press "New liner installed". Set
`SENTINEL_DASHBOARD_PASSWORD=<something>` in `.env` and restart: browsers then ask for it once (any user name).
Traps keep uploading with their own keys. The password travels unencrypted outside Tailscale, so it keeps
passers-by out; it is not a substitute for HTTPS on a real server.

### Keep it running (start at login, restart on crash)

`server/launchd/org.orchardsentinel.server.plist` runs the same command as a macOS LaunchAgent.
It is set up on Nina's MacBook Air; the paths in it are absolute, so edit them for another Mac.

```bash
cp server/launchd/org.orchardsentinel.server.plist ~/Library/LaunchAgents/
launchctl bootstrap gui/$(id -u) ~/Library/LaunchAgents/org.orchardsentinel.server.plist
```

- Logs: `server/data/server.log`
- Restart after changing `.env` or pulling new code: `launchctl kickstart -k gui/$(id -u)/org.orchardsentinel.server`
- Stop for good: `launchctl bootout gui/$(id -u)/org.orchardsentinel.server`

Don't also start `sentinel-server serve` by hand while it's loaded: the second copy can't get port 8000.

## Tailscale on the Mac

Install the Tailscale app, log in with the team account, and turn on MagicDNS in the Tailscale admin console. The Mac's name (e.g. `sentinel-mac`) is what goes in each trap's `server_url`. Campus Wi-Fi usually blocks devices from reaching each other directly; Tailscale gets around that without opening any ports to the internet.

## Try it without a Pi

The device software has a fake camera that draws a liner collecting moths:

```bash
cd device && uv venv --python 3.12 .venv && uv pip install -p .venv/bin/python -e '.[dev]'
# config.toml: backend = "fake", server_url = "http://127.0.0.1:8000", data_dir = "./data", halt_after_cycle = false,
#              [led] enabled = false, [sensors] sht4x = false
for i in 1 2 3 4 5; do .venv/bin/sentinel-cycle --config config.toml --no-halt; done
```

## Better models (optional, needs ~3 GB of downloads)

| Setting | Install | What it does |
|---|---|---|
| `SENTINEL_DETECTOR=flatbug` | `uv pip install -p .venv/bin/python -e '.[flatbug]'` | Pretrained insect detector, which also works on crowded cards. Weights (50 MB) download to `data/models/` on first use |
| `SENTINEL_DETECTOR=yolo` + `SENTINEL_DETECTOR_MODEL=../ml/models/yolo11/<run>/weights/best.pt` | `uv pip install -p .venv/bin/python -e '.[yolo]'` | Our own YOLO11 from `ml/train_yolo.py`. The photo is shrunk to the px/mm the run was trained at, cut into overlapping tiles, and the tiles' boxes merged so an insect on a tile edge counts once. Not the default until a run has been scored on our own liners |
| `SENTINEL_CLASSIFIER=bioclip` | `uv pip install -p .venv/bin/python -e '.[bioclip]'` | BioCLIP 2 zero-shot species ID (model v0) |
| `SENTINEL_CLASSIFIER=bioclip-v1` + `SENTINEL_CLASSIFIER_HEAD=../ml/models/v1/head.npz` | same `[bioclip]` extra | BioCLIP 2 + the linear head from `ml/train_v1.py` (model v1) |
| `SENTINEL_CLASSIFIER=cnn-v2` + `SENTINEL_CLASSIFIER_MODEL=../ml/models/v2/efficientnet_b0.pt` | same `[bioclip]` extra (brings torch + torchvision) | fine-tuned CNN from `ml/train_v2.py` (model v2) |

The default `baseline` detector needs no downloads: it finds the liner's printed grid (which gives the
scale in px/mm and, with a wide lens, how much to straighten the photo), removes the grid lines, and keeps dark blobs 3–30 mm long. Try any detector on
photos with `sentinel-server detect *.jpg --out overlays/ [--detector flatbug|yolo]`.

Whatever the detector, three rules apply to every photo:

- **Only the card counts.** Where the photo shows a pale card inside a strongly coloured trap (the wide
  IMX219 sees the red walls), boxes off the card or within 4 mm of its edge are dropped; the overlay draws
  the card's outline in green. A photo that is all liner is left alone.
- **A photo whose scale is off is left out.** Every photo of a liner has the same px/mm. One that reads
  more than 20% away from the liner's other photos, or shows no grid when they did, is marked failed
  ("photo not used: …") and changes no counts: its boxes would be sized wrongly.
- **A blurred photo is left out** the same way: sharpness under 40% of the liner's other photos
  (repeat shots of one scene vary by about 30%; a blur of 3 px brings it to 20–25%).
- **Species comes from fresh photos.** A moth's photos count towards its species for 72 hours after it is
  first seen; after that it has lost scales to the glue and later photos only keep it in place.
- **One box per insect.** A box lying mostly inside a bigger one (a body inside its wings, one wing of a
  spread moth) is folded into it. On 16 OFM liner photos, Oct 7 2026: 800 → 768 counted for 328 boxed
  moths, 2 moths lost; 7 pinned specimens went from 31 boxes to 25, and 21 to 17.
- **Context is logged with every photo** (`captures.meta`): px/mm, sharpness, share of the card blown out
  by glare, the card's colour, the liner's age in days and how much of the moon is lit, next to the trap's
  own temperature, humidity and battery. `sentinel-server evaluate` sums them up under "Photos".
- **Two more events**, next to `card_full`: `glare` when over 2% of the card is blown out to white
  (insects there cannot be seen: diffuse or re-aim the LED), and `card_old` when a liner passes
  `SENTINEL_LINER_MAX_DAYS` (default 28: our own choice, not a measured limit).

Measured Oct 7 2026 on the M3 Mac, one 3280 × 2464 photo: baseline 4–5 s and 350 MB peak memory; YOLO11s
on 20–24 tiles 10–12 s. At six photos a day neither is a limit. The baseline shrinks the photo to 1,600 px
wide first (7.5 px/mm on the IMX219); working at full size found 1 more of 211 boxed OFM (189 vs 188),
counted 8% fewer false ones and took 2.4 times as long, so it stays at 1,600.
A photo is about 2.2 MB: six a day is 13 MB a day, about 2.4 GB per trap for a 180-day season on the
server, which keeps every photo. The trap keeps its last 200 sent photos (about a month).

On Apple Silicon both run on the Mac's GPU (`mps`). After switching, re-run old photos with
`sentinel-server reprocess --card <id>`.

## Degree days

The trap only measures temperature when it wakes, which is too few readings for accurate daily max/min.
Import daily data from the nearest NEWA station as a CSV with columns `date,tmax_f,tmin_f`:

```bash
.venv/bin/sentinel-server import-weather ithaca_2026.csv --source newa:Ithaca
```

## Tests

```bash
.venv/bin/pytest -q
```

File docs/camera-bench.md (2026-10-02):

# Picking a camera: the bench test

Every candidate camera photographs the same printed checkerboard from the same height, and
`sentinel-camera-bench` turns each photo into numbers we can compare side by side.

## Setup (once)

1. Print `hardware/print/checkerboard.png` at **100 %**. Check one square: it must be 12.0 mm.
   Tape it flat to something stiff.
2. Mark the trap height: lens **150 mm** above the card (above the 110 mm roof peak, the height
   that covers the whole card; see `hardware/TRAP.md`). Use a stack
   of books, a clamp or the mockup trap. Keep that height the same for every camera.
3. Lighting: use the same light for every camera, ideally the trap LEDs, and otherwise one
   lamp. Avoid glare on the paper.

## Shots per camera

| Tag | What | Why |
|---|---|---|
| `centre` | Board in the middle of the frame | Detail, focus, noise |
| `corner` | Board pushed into one corner (entirely in frame) | Lens softness at the edges, where half the liner is |
| `dim` | Lamp off / LEDs at the lowest setting | Dusk shot quality |

Also take one photo of a real moth or a staged liner with each camera, for a look by eye.

## Commands

Webcam on a Mac (the first run asks for Camera permission for your terminal app; allow it
and run again. Index 0 or 1 selects the camera; `system_profiler SPCameraDataType` lists them):

```bash
cd device
uv run --with-editable '.[bench]' sentinel-camera-bench shoot --camera brio101 --backend usb --device 1 --out ../camera_bench
```

On the Pi (webcam on `/dev/video0`, or a Pi camera module):

```bash
sentinel-camera-bench shoot --camera cm3wide --backend picamera2 --out ~/camera_bench
```

Any other camera (phone, a camera with its own app): take the photo there, then score it:

```bash
uv run --with-editable '.[bench]' sentinel-camera-bench score --camera phone --tag centre --image ~/Downloads/IMG_0412.jpg --out ../camera_bench
```

Collect all the `camera_bench/<camera>/` folders on one machine and print the table:

```bash
uv run --with-editable '.[bench]' sentinel-camera-bench compare --out ../camera_bench
```

## Reading the table

| Column | Good | Meaning |
|---|---|---|
| px/mm | ≥ 8 | Nominal detail on the card |
| OFM px | ≥ 50 | Pixels along a 6 mm oriental fruit moth, the smallest target. Below ~30 the classifier is guessing from a blob |
| edge blur mm | ≤ 0.25 | Real sharpness after focus, lens and compression. Much bigger than 1/(px/mm) means the camera is out of focus at 150 mm (common for fixed-focus webcams) or over-compressed |
| contrast/noise | ≥ 30 | Image quality; compare `dim` shots for dusk performance |
| FOV mm / liner fits | fits | Whether the whole liner is in view at this height (`--liner WxL` to change the size) |
| fps | — | Webcams only; not important for stills |

Choose on edge blur and OFM px from the `centre` and `corner` shots first, then on the `dim`
contrast/noise. Resolution on the box counts only if the edge blur says the camera uses it.

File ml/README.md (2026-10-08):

# ML data and experiments

## Quick start: dataset → v0/v1/v2 species ID

```bash
uv venv --python 3.12 .venv && uv pip install -p .venv/bin/python -r requirements.txt
python3 fetch_ami.py --out data/ami --other-moths 60     # ~4,000 photos (AMI / GBIF)
python3 fetch_inat.py --out data/inat                    # ~10,300 photos (iNaturalist, research grade, CC; incl. ~3,000 non-moth bycatch)
.venv/bin/python build_dataset.py                        # merge, de-duplicate, split -> data/dataset.csv
.venv/bin/python segment_moths.py                        # flatbug cutout of each insect (~45 min, resumable)
.venv/bin/python make_trap_style.py                      # paste cutouts onto data/liners/*.jpg -> data/synth/
.venv/bin/python liner_crops.py                          # real insects on other people's liners, at trap px/mm -> data/web_liners/species/
.venv/bin/python build_dataset.py                        # again, to add the trap-style photos and the real-liner crops
.venv/bin/python train_v1.py                             # BioCLIP 2 features -> v0 zero-shot + v1 head -> models/v1/
.venv/bin/python eval_liner_species.py                   # the head on held-out real liners, as the server would treat each crop
.venv/bin/python train_v2.py                             # fine-tuned EfficientNet-B0 -> models/v2/ (ConvNeXt-T, MobileNetV3-L: RUN_ON_CUDA.md)
```

**Classes** (what the server stores): `CM`, `OFM`, `OBLR`, `other_moth` (other tortricids, lesser
appleworm, redbanded leafroller, 60 common NE moths), `other_insect` (non-moth bycatch photographed in
NY: `other_insect` and the `bycatch_*` labels: flies, wasps, beetles, bugs, lacewings, leafhoppers,
spiders) and `debris` (bare liner: grid, glare, shadows; later real leaf bits and insect remains).

**Trap-style photos.** Web photos are sharp, full size and naturally lit. In the trap a CM is ~150 px
long (wide-angle IMX219, ~15 px/mm in the centre, 10–11 at the edges; ~70 px on the old webcam) on a
gridded liner under the trap's LED. `segment_moths.py` cuts each insect out with
flatbug; `make_trap_style.py` pastes it onto real liner photos at its real length in mm and a random
5-16 px/mm, tints it by the liner's light, adds a contact shadow, crops the way the server does
(pad 0.35), then blurs, adds noise and JPEG-compresses. `python make_trap_style.py --preview 48`
writes a contact sheet. Each copy keeps its source photo's split. **Liner photos:** put 640×480 or
larger photos of a *blank* liner, taken by the trap camera, in `data/liners/`. Today there are 3,
all from the old 640×480 webcam in the lab (Sep 24 2026), and all 24,112 trap-style photos are pasted
onto them: the set has never seen the IMX219's resolution, lens or light. Blank-liner IMX219 photos
exist (`data/trap_camera/capture_2026-10-06/`, Oct 6 2026) but were taken before the LED was moved;
once the camera is recalibrated for the new light, put fresh blank-liner photos in `data/liners/` and
re-run `make_trap_style.py`, `build_dataset.py` and `train_v1.py`.

**Photos from the trap itself.** `export_server_crops.py --server ../server/data` writes every insect
reviewed on the dashboard (confirmed/relabelled → that label, rejected → `debris`) into
`data/own/<label>/<card>/`, cropped exactly like the server crops for the classifier.
`--empty-card <card>` adds every detection on a card known to be blank as `debris`; only use it for
photos of a real liner, not bench shots of the room. As of Oct 6 2026 `data/own/` does not exist: the server
holds 6 webcam photos (640×480, Sep 24 and Oct 1 2026) and no reviews, so no model has trained on or been
scored against our own trap.

**Adding our own photos later:** save insect crops as `data/own/<label>/<card>/*.jpg` (labels `CM`, `OFM`,
`OBLR`, `other_moth`, `other_insect`, `debris`; one folder per staged card), list the cards set aside for the final
evaluation in `data/own/locked_test.txt`, then re-run `build_dataset.py` and `train_v1.py`. Only new
photos get embedded. Run `train_v1.py --final` once, at the end, for the report's numbers.

**Don't quote the web-photo test scores as trap accuracy.** BioCLIP 2 was trained on iNaturalist/GBIF
photos (TreeOfLife-200M), so it has likely seen these exact test photos with their names, and they
show whole moths in natural poses rather than moths flattened on a glue liner. Oct 7 2026,
`models/v1` (trained on 6,846 iNat + 2,684 AMI + 16,976 trap-style photos + 2,099 real-liner crops,
C=10, T=1.18), balanced accuracy on the test split: web photos v0 zero-shot 0.67, v1 0.98; their trap-style
copies (webcam liners, 5–16 px/mm) v0 0.54, v1 0.89. A sign the pipeline works, not how well the trap
will do. Earlier heads are kept for comparison: `models/v1-no-liner/` (Oct 2, no real-liner crops: 0.99 and
0.90), `models/v1-2026-10-07a/` (the first Oct 7 head, real OFM and CM crops but no real non-target moths)
and `models/v1-2026-10-07b/` (with the non-target moths, before the field cards and the finished OFM-liner labels).

**Real insects on real liners** (`liner_crops.py`, `eval_liner_species.py`). The web-photo → trap gap is
the main problem in the insect-ML literature (8–16 points on AMI traps), and ours was worse: Oct 7 2026,
the Oct 2 head on other people's liner photos at 15 px/mm found 43% of 162 OFM (19% were counted
automatically as something else) and no debris. `liner_crops.py` turns real-liner photos into crops at trap
resolution (15 and 10 px/mm), 2,309 insects from 123 liners and cards:

- **OFM liners** (trap camera): 478 OFM (the uploader's boxes), 664 other insects and 87 debris (pass-1 labels).
- **CM cards** (phone, full-size photos, 10 px/mm only): 131 CM.
- **PTM liners** (Insect Science delta liners, phone, ~7 px/mm, kept as photographed): 881 potato tuber moths
  and *Tuta*, as `other_moth`. The only real non-target moths on glue in any number.
- **Field cards** (our orchard's Trécé cards, phone): 35 OBLR, 20 OFM, 13 CM, 1 lesser appleworm, 1 other moth.
  The only real-liner OBLR, and a second source of OFM and CM.

**Who labelled what (Oct 7 2026), and what still needs a person's eye.** Pass 1 on the OFM liners is finished:
454 of its 1,361 boxes were labelled by Claude from contact sheets (`labelled_by_claude.csv` beside
`labels.csv` lists each one, 65 marked unsure; the sheets are in `claude_sheets/`; the labels before that are
in `labels.backup-before-claude.csv`). Species on the field-card moths is Claude's reading of the full-size
crops, in `data/field/species.csv` with the sheets in `data/field/claude_sheets/`: 70 of 94 named, 24 left
blank as unsure, `labels.csv` untouched. Neither has been checked by someone who knows the moths. Tan
leafrollers with oblique bands were called OBLR, grey moths with wavy lines and a dark wing tip CM, small plain
dark-grey moths on the April card OFM; a threelined leafroller or a lesser appleworm among them would look
much the same in these photos.

They join `dataset.csv` as source `liner`, grouped by liner or card. Held out and never trained on:
`liner_crops.TEST_GROUPS` for the OFM liners and CM cards (a third of their moths, including `train_yolo.py`'s
test liners), a hash-picked quarter of the PTM photos (97 of 881 moths), and for the field cards those in
`data/field/test_cards.txt` (CM) plus the April 2025 OFM card and the June 2024 OBLR photos, so every target
has field moths no head trained on. Liners with a fifth of the remaining crops are val, and `train_v1.py`
picks C and the temperature T on them instead of on web photos.

Held-out liners and cards, Oct 7 2026, found / auto & wrong ("auto & wrong" is a wrong label at confidence
≥ 0.80, which the server counts with no one looking):

| true class (crops), set | px/mm | Oct 2 head (web + trap-style) | `v1-2026-10-07b` (+ OFM, CM, PTM liners) | `models/v1` (+ field cards, finished pass 1) |
|---|---|---|---|---|
| OFM (162), OFM liners | 15 | 0.43 / 0.19 | 0.94 / 0.00 | 0.94 / 0.00 |
| OFM (162), OFM liners | 10 | 0.40 / 0.30 | 0.92 / 0.01 | 0.90 / 0.01 |
| OFM (19), field card | 10 | | 18 of 19 / 0 | 18 of 19 / 0 |
| CM (37), CM cards | 10 | 0.89 / 0.00 | 0.89 / 0.00 | 0.92 / 0.00 |
| CM (10), field cards | 10 | | 10 of 10 / 0 | 10 of 10 / 0 |
| OBLR (14), field cards | 10 | | 14 of 14 / 0 | 14 of 14 / 0 |
| other moth (97), PTM liners | ~7 | 0.07 / 0.53 | 0.96 / 0.00 | 0.92 / 0.01 |
| other insect (127), OFM liners | 15 | | 0.80 / 0.02 | 0.85 / 0.02 |
| other insect (127), OFM liners | 10 | | 0.72 / 0.07 | 0.81 / 0.03 |
| debris (12), OFM liners | 15 | | 6 of 12 | 7 of 12 |

Two things in that table carry the weight. The other-moth row: before the PTM liners a head trained on real
OFM had learnt that a moth on a real liner is OFM (71 of 97 unseen non-target moths called OFM). And the
field-card rows in the middle column: that head had never seen a field-card moth or a real-liner OBLR, and
it agrees with the species read off the photos on 42 of 43. Two readings that could share a mistake, but
they were made separately.

A check on photos from no set at all (Oct 7 2026): 24 codling moths boxed by hand on two liner photos from
Wikimedia Commons and iNaturalist (`data/web_liners/species/independent/`, oblique views, ~85 px moths).
`v1-2026-10-07b` called 18 CM, 4 other moth, 2 OFM, none wrong at ≥ 0.80.

Read all of this for what it is: the species is an uploader's claim or a reading from a photo, the cameras
are not ours, most classes lean on one source (the PTM liners have a green grid, the OFM liners a black one),
the field-card numbers are 10–19 moths each, and the same held-out crops are looked at each time a head is
compared. A development check; the report's numbers still come from our own locked cards.

**Training somewhere else.** `data/` is not in git, so `make_bundle.py` packs the scripts, `dataset.csv`,
every image it lists (web photos shrunk to 512 px), the cached features, the current head and what
`train_yolo.py` reads into `data/bundle/orchard-train.zip` (about 1.8 GB). [RUN_ON_CUDA.md](RUN_ON_CUDA.md) has
the commands for a machine with a CUDA GPU: three v2 runs (`efficientnet_b0`, `convnext_tiny`,
`mobilenet_v3_large`), v1, and the detector, which now has all 31 OFM liner photos. `train_v2.py` keeps the
epoch that does best on real-liner val crops and saves a temperature with the weights; the server applies it.

**The CUDA runs (Oct 8 2026, RTX 3060 Ti under WSL).** Three fine-tuned CNNs, 20 epochs each, scored on the
same 785 held-out real-liner crops as `models/v1` (15 and 10 px/mm together), each with its own temperature:

| | `models/v1` linear head | `v2/` EfficientNet-B0 | `v2-convnext/` ConvNeXt-T | `v2-mobilenet/` MobileNetV3-L |
|---|---|---|---|---|
| all crops right | 0.89 | 0.90 | 0.87 | 0.90 |
| wrong at ≥ 0.80 (counted with no one looking) | 1.3% | 4.5% | 6.6% | 4.2% |
| OFM, OFM liners (324) | 299 | 292 | 291 | 301 |
| **OFM, held-out field card (19)** | **18** | **3** | **6** | **4** |
| CM, CM cards (37) | 34 | 37 | 37 | 37 |
| CM, field cards (12) | 12 | 12 | 12 | 12 |
| OBLR, field cards (17) | 17 | 17 | 17 | 17 |
| other moth, PTM liners (97) | 89 | 97 | 97 | 97 |
| other insect, OFM liners (254) | 211 | 238 | 206 | 218 |
| debris, OFM liners (24) | 17 | 10 | 17 | 16 |

**v1 stays.** The CNNs match it on average and are better on bycatch and on sets they trained a part of, but
on the one OFM card from a different camera they call the moths other moth or CM, a third of them at ≥ 0.80.
Every OFM they trained on came from one trap camera, and fine-tuning the whole network learnt that camera;
the frozen BioCLIP features did not. That is the single-source warning above coming true, and it would not
show in any of the three tables `train_v2.py` prints, where the field card is 19 crops among 343 OFM. Their
wrong-at-0.80 rate is also 3–5 times v1's. Averaging all four models gets 0.93 of crops right and 0.6% wrong
at ≥ 0.80, but only 10 of the 19 field-card OFM. The field-card species are Claude's reading of the photos, so
a wrong reading of that card would change this; v1 and that reading were made separately and agree.
v1 retrained on the CUDA machine (`models/v1-cuda/`) gives the same tables as the Mac's to within a crop or two.

**Detector on the same machine** (`models/yolo11/yolo11s-ppm12-cuda/`, 31 training photos with the finished
OFM-liner labels, 7 val, the same 4 test photos, stopped at epoch 106). At its saved confidence (0.49) on the
test photos: moth precision 0.79, recall 0.74; other insect 0.82, 0.54; debris 0 of 13. The Oct 7 run with
half the labelled photos (`yolo11s-ppm12-blank`) had moth 0.77, 0.80 and other insect 0.86, 0.47. Four test
photos cannot separate those: twice the labels did not visibly improve moth detection, and debris is still
not found (225 training boxes).

**OFM is the weak class on web photos.** There are 117 OFM web photos from 71 observations; the test
split has 12 photos from 8 observations (96 trap-style copies). On those trap-style copies the Oct 7 head
found 89% of OFM at precision 0.32 (the same as the Oct 2 head): most crops it calls OFM there are CM or
other moths.

**Using the model in the server:** in `server/.env` set `SENTINEL_CLASSIFIER=bioclip-v1` and
`SENTINEL_CLASSIFIER_HEAD=../ml/models/v1/head.npz`, and install the server's `[bioclip]` extra. As of Oct 6
2026 this has not been done: the server runs `SENTINEL_CLASSIFIER=none` and its venv has no torch, so species
ID has only ever run from the scripts in `ml/`.

**Photos of used field cards** (phone shots of real liners, e.g. Trécé Pherocon VI cards from the
orchard; full-resolution originals, not the copies a chat app makes):

```bash
cp ~/Downloads/<folder>/*.jpg data/field/inbox/
.venv/bin/python crop_field_cards.py          # flatbug boxes every insect -> data/field/labels.csv, crops/, cutouts/, boxes/
.venv/bin/python label_field_cards.py         # label in the browser: http://localhost:8765
```

`crop_field_cards.py` takes px/mm from each card's printed grid (`--grid-mm`, default 25), measured
around each insect so a card shot at an angle still gets the right scale. The labelling page has two
passes. Pass 1 (anyone): moth / other insect / debris, Delete for things that aren't on the card or
aren't insects, B (or the Draw box button) then drag to box an insect flatbug missed, drag a box's
handles to fix it, ⌘Z to undo. Drag or two-finger scroll pans; pinch, wheel or double-click zooms; F fits.
Pass 2 (a trained eye): the species of every `moth`. `labels.csv` records which boxes flatbug got
right, which it got wrong (`skip`), which needed fixing (`flatbug-edited`) and which it missed
(`manual`), which is also flatbug's score on field cards. Oct 2 2026 labels, 11 cards, phone
resolution: 60 of 94 moths found (64%), worst on pale OBLR on a white card; 7 of 81 boxes were not
insects (leg clumps, a leaf bud, the lure).
Leg clumps and wing bits on the card are `debris`, not deleted: the trap sees them too.
These are real moths on glue but not our liner or camera, so they stay apart from `data/own/`.
Insects and debris with species-free labels train the classifier through `make_trap_style.py
--field` (cards in `data/field/test_cards.txt` are held out); `eval_field_cards.py` then scores
`models/v1/head.npz` on every labelled crop as moth / other insect / debris, at the trap camera's
resolution and as photographed, with crops it trained on reported apart (`data/field/eval.md`).
`--mask-neighbours` greys out the other boxes inside each crop first. Oct 2 2026, `models/v1`, crops it
never trained on, shrunk to 8 px/mm (the trap camera is ~15): 92/94 moths, 8/9 other insects, 2/3 debris;
masking changed nothing overall. The non-moth part of that is 12 crops from two cards. Real debris is
not recognised: of the 6 debris crops whose copies *were* in training, none was called debris (5 other
insect, 1 moth), so 2 of 9 in all. Species is unchecked: no pass-2 labels exist yet, and the 94 moths
were called 42 OBLR, 24 OFM, 16 CM, 10 other moth, 2 other insect at a median confidence of 0.99.
Oct 7 2026, the Oct 7 head (with real-liner crops), same crops shrunk to 15 px/mm: 94/94 moths, 7/9 other
insects, 0/3 debris not in training (0/6 of those in training); the moths' species calls keep the same
card-by-card pattern, so the OFM liners did not teach it to call every moth OFM.

**Other people's liner photos** (`data/web_liners/`, gitignored; its README lists every source and
license). Collected for liners like ours: white delta liners with a ~25 mm printed grid. Public Roboflow
sets with hand-drawn moth boxes: Trécé CM cards, OFM trap-camera liners, Insect Science delta liners,
grape-moth cards; photos that don't look like our liner are kept apart in `nongrid/`.

```bash
.venv/bin/python eval_detector_roboflow.py --trap-ppm 8   # baseline and flatbug vs the boxes, native and at trap px/mm
.venv/bin/python eval_detector_combine.py                 # what a shape filter and baseline+flatbug add
.venv/bin/python import_roboflow_labels.py ofm-ervins     # a set's boxes + detector boxes -> label_field_cards.py folder
.venv/bin/python label_field_cards.py --data data/web_liners/label/ofm-ervins --port 8767
.venv/bin/python carry_liner_labels.py --data data/web_liners/label/ofm-ervins --write   # labeller stopped first
```

Oct 2 2026, recall of boxed moths: the server's baseline detector found 89–94% on the OFM liners and
full-size CM cards, flatbug 43–60% (20% on OFM at 8 px/mm); both miss most moths under ~25 px long. Where
the baseline's recall is good its count is not: it reported 2.3–2.8 times the boxed moths on the OFM liners
and 9.5–12.5 times on the full-size CM cards (bycatch included), so a count needs the classifier or review. On
the other two sets the baseline does far worse: 30% of boxed moths on the Insect Science liners (native,
7.3 px/mm) and 52% on the grape-moth cards (native, 8.4 px/mm), 6% and 17% at 8 px/mm; flatbug under 10%
on both. A shape filter on baseline boxes (short side ≥ 2.5 mm, long/short ≤ 3.5) cut its unmatched boxes
per photo from 60 to 32 on the full-size CM cards and from 22 to 13 on the OFM liners (native), losing 1
of 131 and 5 of 482 moths; it is not in the server's detector yet. Only the target moth was boxed in
these sets, so precision is a lower bound until the bycatch is labelled. Pass 1 on the OFM set: 14 of 31
photos done, 454 boxes left (Oct 2 2026); `carry_liner_labels.py` not yet run, no pass 2 anywhere. `recover_roboflow_originals.py` moved stretched
export boxes back onto original uploads (already run). Trap-camera sets photograph the same liner on
several days: `carry_liner_labels.py` copies labels between them, and train/test splits must keep a
liner's (or a card's) photos together.

**YOLO11 detector and trying models** (`train_yolo.py`, `model_playground.py`):

```bash
.venv/bin/python train_yolo.py                                          # hand-checked liner photos only -> models/yolo11/<run>/summary.json
.venv/bin/python train_yolo.py --synth 3000 --out data/yolo-synth --epochs 50   # plus AMI/iNat cutouts pasted on tiles
.venv/bin/python train_yolo.py --blank 'data/trap_camera/capture_2026-10-06/calibrated_*.jpg' --blank-ppm 15.3   # plus blank trap-camera liners, no boxes
.venv/bin/python model_playground.py                                    # http://localhost:8770: any detector/classifier on a photo or a screen capture
```

`train_yolo.py` splits the fully labelled photos three ways, by card/liner: **test** (`data/field/test_cards.txt`
plus two OFM liners; scored once, after training), **val** (about 15% of the rest, the same photos every run;
training stops on them and keeps the epoch that does best on them) and train. Only the `test` block of
`summary.json` is a score to quote.

Oct 2 2026, yolo11s at 12 px/mm, 25 fully labelled photos (11 field cards + 14 OFM liners): 21 trained, 2 field
cards + 2 OFM liners held out: mAP50 0.55 over the three classes (precision 0.49, recall 0.59); moth 0.89, other
insect 0.74, debris 0.04 (89 training boxes). **These are optimistic:** that run had no separate val set, so the
same 4 held-out photos also picked the best of 150 epochs. Not yet re-run with the three-way split (16 train /
5 val / the same 4 test photos); `data/yolo/` and `models/yolo11/yolo11s-ppm12/` on disk are still the old two-way
run. Replace these numbers when it is. The `--synth 3000` run was stopped at epoch 7 of 50 and has no score.

**Oct 7 2026, the first run with a test score** (`models/yolo11/yolo11s-ppm12-blank/`, data in `data/yolo-blank/`):
yolo11s at 12 px/mm, 16 photos trained + 150 blank trap-camera tiles, 5 val, 4 test (2 field cards + 2 OFM liners,
498 boxes), overlap 224, stopped at epoch 141. On the test photos: mAP50 0.52 over the three classes; moth 0.82,
other insect 0.72, debris 0.01 (13 test boxes, 112 in training). At the settings chosen on val (confidence 0.425, NMS
IoU 0.5): moth precision 0.77, recall 0.80; other insect 0.86 and 0.47; debris never found. The Oct 2 figures above
(moth 0.89) were on photos that also picked the checkpoint; on val this run scores moth 0.92, so the honest number
is about 0.1 lower than the flattering one. Through the server's detector on IMX219 photos: 0 boxes on the empty
liner (4 with the Oct 2 weights), but that photo's own tiles were in training as blanks, so it shows the blanks were
learned, not that a new empty liner would be clean. It finds only 1 and 2 of the 7 pinned specimens: they are
15–45 mm, far larger than anything it trained on, and say nothing about 6–14 mm moths. Still no target-size moth
from the trap camera to test on.

**Oct 8 2026, twice the labelled photos** (`models/yolo11/yolo11s-ppm12-cuda/`, data in `data/yolo-cuda/`, on an RTX
3060 Ti): the same settings and the same 4 test photos (498 boxes), but 31 photos trained (2,888 boxes: 1,036 moth,
1,627 other insect, 225 debris) + the same 150 blank tiles, 7 val; stopped at epoch 106 (patience 40). On the test
photos: mAP50 0.51 over the three classes; moth 0.77, other insect 0.73, debris 0.03. At the settings chosen on val
(confidence 0.49, NMS IoU 0.5): moth precision 0.79, recall 0.74 (Oct 7: 0.77, 0.80); other insect 0.82 and 0.54
(0.86, 0.47); debris 0 of 13. On its own val photos moth scores 0.90, so the val-to-test drop is the same as before.
Four test photos cannot tell the two runs apart; what they do show is that doubling the OFM-liner labels did not
lift moth detection on the field cards and liners held out, and that 225 debris boxes are still not enough to
find debris. Not yet run through the server on IMX219 photos.

Other options, none used in a scored run yet: `--imgsz 800` enlarges the tiles for the network (modest gains
for small insects elsewhere); `--one-insect-class` trains `insect` + `debris` instead of three classes (a generic
insect detector found 80% of species it had never seen, and the classifier names them anyway; our `debris` class
scored 0.04). After training, the confidence cut and the NMS IoU are chosen on the val photos by best F1 and saved
as `predict` in `summary.json`, with precision and recall at that cut per class; the server reads them. Oct 7 2026,
the Oct 2 weights on their 4 val photos (the ones that also picked the checkpoint): NMS IoU 0.5 → moth F1 0.84,
0.7 → 0.84, 0.9 → 0.74; best confidence 0.14, not the 0.25 default. A setting tuned for another trap (0.9 in
Yolo-pest) would have cost us.

Tiles overlap by at least the longest single moth (18 mm: 224 px at 12 px/mm; it was 160 px for the Oct 2 run),
so every insect is whole in some tile. `--blank` adds blank-liner photos from the trap camera as tiles with no
boxes: the grid, glare, walls and clips the detector must learn to leave alone. The Oct 7 and Oct 8 runs use both.

The server can run a YOLO run: `SENTINEL_DETECTOR=yolo` with `SENTINEL_DETECTOR_MODEL=<run>/weights/best.pt`
(`docs/server-on-mac.md`); the playground merges tiles the same way the server does. Oct 7 2026, the Oct 2 weights
through the server's detector on IMX219 photos (15 px/mm, shrunk to 12): 4 false boxes on the empty liner
(`capture_2026-10-06/calibrated_1.jpg`) and 9 boxes for the 7 pinned specimens under the new light
(`capture_bugs_light2_2026-10-06/calibrated_1.jpg`). Two photos, not a score; the false boxes on a blank liner are
what `--blank` is for.

## What insect-ML papers found, and what we do about it

Every finding in the Oct 6 2026 literature notes, with what was changed, tested, left alone or could not be
done: [docs/ml-research-status.md](../docs/ml-research-status.md). What it changed in this folder:

- **Real-liner crops in training and as a held-out test** (`liner_crops.py`, above): the one change that moved
  the score.
- **C and a temperature picked on real-liner val crops** (`train_v1.py`); the head carries the temperature and
  the server, the playground and the scorers apply it.
- **`eval_liner_species.py`** reports recall with a 95% interval, what the server would do with each crop, and
  recall by crop size.
- **`clean_dataset.py`** lists web photos far from the rest of their species (label cards, blank frames, moths
  that are a dot, pinned specimens) and photos the head would label differently, with contact sheets in
  `data/clean/`. It excludes nothing: a person copies the junk into `data/exclude.csv` (`path,why`), which
  `build_dataset.py` leaves out along with its trap-style copies. Oct 7 2026: 220 odd photos and 21 possible
  label errors of 13,564; leaving all 220 out did not change the real-liner score.
- **`train_v2.py`** has RandAugment, mixed resolution, a warm-up epoch and label smoothing 0.1, and reports
  the held-out real-liner test. Run Oct 8 2026 on three architectures (the CUDA runs, above): none replaces v1.

Tried on the held-out liners and dropped (Oct 7 2026, numbers in the status page): a moth / non-moth gate
before the species head, a head on the 15 fine labels, capping labels at 1,000 photos, leaving out spiders,
leaving out the AMI photos, a temperature fitted on web photos, zero-shot life-stage filtering, black-padded
tight crops.

## Get training photos from AMI (primary external source)

```bash
python3 fetch_ami.py --out data/ami --dry-run              # counts only (~330 MB of metadata, cached)
python3 fetch_ami.py --out data/ami --other-moths 60       # download: our moths + 60 common NE moths
```

Checked Sep 23 2026 (adults, all AMI splits): CM 729, OBLR 1,300, **OFM 72**, lesser appleworm 84,
redbanded leafroller 1,300, 900 "other moth" photos at 60 × 15. A few links (the SCAN museum portal)
refuse automated downloads; the script logs them in `manifest.csv` and moves on. `manifest.csv`
also keeps every photo's source URL, for credits.

These are photos of live or pinned moths, **not** moths on sticky liners. Use them to train only,
never to report accuracy. Accuracy numbers come from our own staged-card photos, split by card.

## Model versions (see the architecture page)

| Version | Detector | Species ID | Where it lives |
|---|---|---|---|
| v0 | baseline OpenCV → flatbug | none → BioCLIP 2 zero-shot | `server/sentinel_server/pipeline/` (`SENTINEL_DETECTOR`, `SENTINEL_CLASSIFIER`) |
| v1 | flatbug | BioCLIP 2 features + logistic regression (`train_v1.py`); InsectNet / DINOv2 comparison still to do | `ml/train_v1.py` → `models/v1/head.npz`, server `SENTINEL_CLASSIFIER=bioclip-v1` |
| v2 | fine-tuned flatbug or YOLO11 (YOLO11: three scored runs, the latest Oct 8 2026; playground and `SENTINEL_DETECTOR=yolo`) | fine-tuned EfficientNet-B0 / ConvNeXt-T / MobileNetV3-L (`train_v2.py`, from Patti's MobileNet script); trained Oct 8 2026, none beats v1 on OFM from a second camera | `models/yolo11/<run>/`, `models/v2/<arch>.pt` (server `SENTINEL_CLASSIFIER=cnn-v2`) |

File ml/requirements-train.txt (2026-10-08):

# What a training machine needs (RUN_ON_CUDA.md). Install torch and torchvision first, from the wheel that
# matches the machine's CUDA: https://pytorch.org/get-started/locally/
numpy>=2.0
pillow>=10.0
scikit-learn>=1.4
open_clip_torch>=2.24          # train_v1.py, eval_liner_species.py: BioCLIP 2
opencv-python>=4.9             # train_yolo.py reads the liner grid
ultralytics>=8.4               # train_yolo.py: YOLO11

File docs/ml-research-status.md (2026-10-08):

# Insect-ML research: what we did with each finding

Status of every item in "Moth Monitoring Machine Learning (Data, Classification, Evaluation)" (Oct 6 2026)
against this repo, as of Oct 8 2026. Start with what could **not** be done; the full item-by-item list follows.
The imaging, detection and counting notes are in [cv-research-status.md](cv-research-status.md).

Words used: **Done** = changed in code or docs on Oct 6–7 2026 and tested. **Had** = already how the repo
worked. **Tested** = tried on our data, with the result; "kept" or "dropped" says what we did. **Not ours** =
about light traps, other hardware or other pests. **Open n** = see the first two sections.

Every "tested" number is the v1 species head (BioCLIP 2 features + linear head) on other people's liner photos,
on liners no head trained on (`ml/eval_liner_species.py`, 15 px/mm unless said): 162 OFM, 87 other insects,
4 debris from OFM trap-camera liners and 37 CM from phone photos of CM cards. The species is the uploader's
claim and the camera is not ours, so they choose between options; they are not trap accuracy. The v2 rows
(Oct 8 2026) are fine-tuned CNNs on the later, larger held-out set (785 crops, field cards included), next to v1 on the same crops.

## Could not be done here

| # | Item | Why not | What would settle it |
|---|---|---|---|
| 1 | Training and testing on our own trap, across a season, with decayed moths and crowded liners | `ml/data/own/` does not exist: the server holds 6 webcam photos and no reviews. Everything "real" in training is other people's liners | Run the trap, review on the dashboard, `export_server_crops.py`, lock test cards, `train_v1.py --final` |
| 2 | Species checked by someone who knows the moths | Real-liner species now covers all three targets, but from an uploader's claim (OFM liners, CM cards, potato tuber moth) or from Claude reading the field-card photos on Oct 7 2026 (`ml/data/field/species.csv`: 35 OBLR, 20 OFM, 13 CM, 24 left unsure). A head that never saw those cards agrees on 42 of 43 held-out moths, which is two readings, not a check. No look-alike tortricid on glue except one lesser appleworm | A trained eye over `ml/data/field/claude_sheets/` and `species.csv` |
| 3 | The species that really land in each lure's trap here | The papers' look-alike lists are European or for other pests (*Synanthedon myopaeformis*, *Cacoecimorpha pronubana*, *Mythimna*). I have not put names in the fetch scripts from memory; the right list is whatever pass 2 finds on the Geneva field cards, checked with an entomologist | Pass 2, then add the species to `fetch_inat.py` as `lookalike_*` |
| 4 | OFM against lesser appleworm at trap resolution | With lesser appleworm in training, 39 of 132 trap-style lesser appleworm copies are still called OFM (1% at ≥ 0.80; the rest go to review). No real-liner lesser appleworm to check against. The file `OFM and LAW.jpg` among the field cards has 2 moths | Pass 2; if they stay inseparable at 15 px/mm, review every OFM near the biofix (now flagged, see below) |
| 5 | 128 vs 224 px input, and a small custom CNN | The architecture comparison itself was run on Oct 8 2026 (EfficientNet-B0, ConvNeXt-T, MobileNetV3-L on an RTX 3060 Ti): none beats the BioCLIP 2 linear head, and all three fail OFM from a second camera (3–6 of 19 against 18), see `ml/README.md`. Input size and a from-scratch CNN were not tried: with every OFM from one camera they would fail the same way | A second source of OFM first |
| 6 | Intermediate pre-training on a pest dataset (COCO → IP102 → ours) | Detector-side, needs the IP102 download and GPU hours, and with 25 labelled photos the labels are the limit, not the starting weights (rule in `.claude/rules/ml.md`) | After the OFM liners are fully labelled and a YOLO run is scored |
| 7 | Attention module on the detector (CBAM) | Same reason: an architecture change before the data is fixed | Same |
| 8 | Trap-style training photos on the trap camera's own liner | The blank IMX219 liner photos predate the LED move ([cv-research-status.md](cv-research-status.md), item 3) | Recalibrate, photograph a blank liner, re-run `make_trap_style.py`, `build_dataset.py`, `train_v1.py` |
| 9 | Carrying classifier error into the counts and the biofix as a model | Needs the head's error rates on our trap. The dashboard now collects them (spot checks, below) but there are none yet | A few weeks of spot checks, then correct counts by the agreement rate |
| 10 | R² of daily counts, false positives by cause, and whether a spray decision would change | `sentinel-server evaluate` reports count accuracy per liner, mean error per trap-day, false moths by cause and the biofix date; it has never had real truth files. R² is not computed (one trap, few days: mean error says more) | Truth counts from locked cards |
| 11 | Watching for drift after deployment | Nothing deployed. The two signals to watch are built: spot-check agreement per trap, and the share of catches waiting for review | A season; re-score on locked cards after any change of liner, lure, camera or light |
| 12 | Throwing out bad web photos | `clean_dataset.py` lists 220 photos far from the rest of their species and 21 the head would label differently; a person has to look, because good photos on odd backgrounds are in the same list. Dropping all 220 blind changed nothing on real liners (OFM 0.95, CM 0.89 either way) | Look at `ml/data/clean/*.jpg`, copy the junk into `ml/data/exclude.csv` |
| 13 | A debris score | 4 held-out debris crops (2 found; 95% interval 15–85%) and 9 on field cards (0 found) | Debris from our own liners; rejected detections on the dashboard become `debris` through `export_server_crops.py` |
| 14 | Grouping unknown insects to speed up labelling (morphospecies clustering) | Not built. It would help most on the 454 unlabelled boxes of the OFM liners, but the labeller keeps `labels.csv` in memory, so suggestions cannot be written into it while it is open | A `suggested` column the labeller shows; needs the labeller changed |
| 15 | Results by region | One region (NY). The look-alike and bycatch photos are already NY-only | A second site |
| 16 | Storing results as Darwin Core / Camtrap DP | Not built: it is a biodiversity-data standard, and this trap's output is a count and a date for one grower. The database already keeps every detection's class probabilities and model version | An export command, if the data is ever shared |
| 18 | More correctly labelled photos of the targets | Checked Oct 7 2026: iNaturalist has 58 research-grade OFM observations in the world and 130 of lesser appleworm, GBIF 59 and 44 with images; we hold them all. CM and OBLR have ~10,000 each and we use 2,000; capping at 1,000 changed nothing, so more would not either. The USDA stored-product sticky-trap set (1,739 hourly photos of one Indianmeal moth trap) has no per-insect labels in its public files | Our own trap |
| 19 | An OFM check from a second source | Every public OFM-on-liner photo found is in the one trap-camera set; NC State's OFM card photo is 600 × 401 px | Our own trap, or a photo of an OFM liner from the Geneva station |
| 17 | Comparing with Trapview's reported precision (> 90%) | Vendor number on their traps; ours needs items 1 and 10 first | Item 10 |

## Needs your decision

- **Which biofix runs the degree-day clock.** The trap page now shows the biofix from all counted catches, as
  before, and says "Provisional" when it rests on catches the model was unsure of, with the date from
  confirmed catches alone beside it. The clock still starts from the first. Starting it from confirmed
  catches only is safer against a false start and later whenever nobody reviews.
- **Spot-check rate.** One in ten automatic labels now also goes to the review queue
  (`services.AUDIT_EVERY`). More gives a tighter error estimate and more clicking.
- **Switching the classifier on.** The server still runs `SENTINEL_CLASSIFIER=none` and its venv has no
  torch. Nothing here changes what the running server does until that is set.
- **The 220 odd photos** (item 12).

## What worked

| Finding | Status | What we do |
|---|---|---|
| RandAugment + mixed resolution (trap accuracy 51.5% → 71.9%) | Done / Tested, v1 kept | `train_v2.py`: RandAugment and `MixRes` (half the photos shrunk to a 48–160 px crop and enlarged back). v1's features are frozen, so its version is the 5–16 px/mm trap-style set and real-liner crops at two resolutions. Oct 8 2026: EfficientNet-B0, ConvNeXt-T and MobileNetV3-L trained with it match v1 overall on the 785 held-out real-liner crops but find 3–6 of 19 OFM on the held-out field card (v1 18), so v1 stays |
| Black padding of crops at inference | Tested, kept ours | AMI padded to avoid stretching a non-square crop. Ours is already a square cut from the photo with liner around the insect, the same framing as the training crops. Same head, held-out OFM liners: our crop finds 0.94 of OFM and 0.80 of other insects; a tight box padded black 0.82 and 0.64; a tight box stretched to square 0.62 and 0.52, with 11% auto-and-wrong. So AMI's point holds (pad, never stretch) and the context crop is better still for a head trained on context crops |
| Mixing target-domain data into training (5% → +13–15 pts) | Done | `liner_crops.py`: 1,611 real-liner crops, 6% of training, now with 881 real non-target moths (potato tuber moth liners): without them the head called 71 of 97 unseen non-target moths OFM, with them 3. Numbers for the first step: OFM found 0.43 → 0.96, counted automatically as something else 0.19 → 0.00; CM 0.89 → 0.89 (10 px/mm). Cost: other insects found 0.97 → 0.80, the rest mostly called OFM below 0.80 |
| Foundation-model prior (BioCLIP 2) | Had | v1 |
| Distilling BioCLIP 2 into a small net | Not ours | Species ID runs on the server, not the Pi |
| GBIF / iNaturalist transfer learning | Had | 13,564 web photos; alone they find 3% of real OFM, so never alone |
| Regional models + per-species cap (1,000) | Had / Tested, dropped | Look-alikes and bycatch are NY-only. Capping every label at 1,000: OFM 0.94, CM 0.95, others the same, val slightly worse (0.732 vs 0.744). Class weights already balance; no cap |
| Label smoothing, AdamW + cosine warm-up | Done / Tested, v1 kept | `train_v2.py`: smoothing 0.1, one warm-up epoch; same Oct 8 runs |
| Separate moth / non-moth filter | Tested, dropped | A moth / other insect / debris head first, then species among moths: OFM found 0.74 (from 0.95), CM 0.84 (from 0.89), auto-and-wrong 1.7% (from 0.6%). One head does better; "called a moth" is in every table of `eval_liner_species.py` |
| ConvNeXt-B / ViT-B/16 | Tested (ConvNeXt-T), dropped | Oct 8 2026, ConvNeXt-T fine-tuned: 0.87 of held-out real-liner crops right (v1 0.89), 6 of 19 field-card OFM (v1 18), 6.6% wrong at ≥ 0.80 (v1 1.3%). ViT-B/16 not tried: same single-camera OFM problem |
| Small custom CNN with heavy augmentation on tiny data | Open 5 | Their comparison was against large nets trained end to end; a frozen foundation backbone is the other answer to tiny data and is what v1 is |
| Attention module on a lightweight detector | Open 7 | |
| Hierarchical transfer COCO → IP102 → target | Open 6 | |
| Simple open-set scoring (max softmax + temperature) | Done | `train_v1.py` fits a temperature on real-liner val crops (T = 1.65) and saves it in the head; server, playground and scorers divide logits by it. Fitted on web photos it came out 0.9–1.1 and did nothing |
| Expert-curated outlier species; more species beats more images | Had / Open 3 | `other_moth` is NY tortricids across many species plus 60 common NE moths, lesser appleworm and redbanded leafroller, not a generic set |
| Anomaly / OOD filter on detections | Had | The `debris` class, the review and unknown bands, and two-photo confirmation. Not measurable yet (Open 13) |
| Hierarchical output, stop at the confident rank | Done | Below 0.80 a catch is "the model's guess" and waits for review; the biofix says when it depends on such catches. No new label was added: the six classes are fixed across the repo |
| Morphospecies clustering + human review | Open 14 | |
| Active learning loop | Done | Review queue → `export_server_crops.py` → `data/own/` → `train_v1.py` was there for unsure catches. Added: one in ten sure catches is also reviewed, so confident mistakes get corrected and become training data too |

## What didn't work

| Pitfall | Status | How we avoid it |
|---|---|---|
| Training only on GBIF / iNaturalist / museum photos | Done | Trap-style copies (had) and real-liner crops (new). Measured here: web photos alone 3% of real OFM, with trap-style 43%, with real-liner crops 96% |
| Raising input resolution because web accuracy rises | Done / Open 5 | BioCLIP is fixed at 224 and our crops are 110–260 px. Note in `train_v2.py` to compare `--size 128` on real liners. Recall by crop size is now in the report: OFM 13/15 under 80 px, 281/292 at 80–180 px |
| ConvNeXt with no prior and no trap data | Had | v1 has both |
| Large pretrained nets fine-tuned on ~2,000 images | Had / Tested, dropped | v1 trains 4,600 weights on frozen features. v2 fine-tunes on 27,000 photos with heavy augmentation; Oct 8 2026 it did not beat v1: all three CNNs learnt the one trap camera that every training OFM came from (3–6 of 19 OFM from a second camera, v1 18) |
| Forcing a species label on everything | Done | Statuses auto / review / unknown were there; the temperature makes them mean something; the biofix now shows when it rests on unconfirmed catches. Unseen look-alike test below |
| Complex open-set methods | Had | None used |
| Generic outlier data | Had | None used |
| Adding arachnids to the class list | Tested, kept | Without the spider photos: OFM 0.95, CM 0.89, other insects 0.80, identical. Spiders do land on liners, so they stay in `other_insect` |
| Pooling distinct species into one class | Tested, kept pooled | A head on the 15 fine labels, added up to 6 classes: OFM 0.30 (from 0.46), CM 0.64–0.76 (from 0.82), on the earlier head. The pooled classes are what the grower needs and they score better |
| Visually mixed coarse classes ("beetle", "bug", "other") | Tested, kept | Same test. `other_insect` finds 0.80 of real bycatch; it needs to be "not a moth", not a name |
| Non-selective lures with a species classifier | Had | Species-specific pheromone lures, one per trap; the lure mask keeps the lure out of the count |
| Mimics and close relatives | Tested / Open 3, 4 | Lesser appleworm left out of training entirely: 27% of its web photos and 39% of its trap-style copies are called OFM, but 3% reach 0.80; max-softmax separates it from known species at AUROC 0.96 (web), 0.85 (trap-style). So an unseen look-alike mostly lands in review, not in the count |
| Damaged or decayed specimens | Done / Open 1 | The tracker votes on species only in a moth's first 72 h (CV side). The real OFM liners are days old and now train the head. Nothing aged for CM or OBLR |
| Fully automatic counts | Done | Review queue, spot checks, provisional biofix |
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

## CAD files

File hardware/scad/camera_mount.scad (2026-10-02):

// Orchard Sentinel: camera mount that sits in the delta trap's roof apex.
// A wedge that fills the top of the "V", with a pocket for the Camera Module 3 Wide
// (lens facing straight down, out of the open pocket) and a channel for the ribbon cable,
// which leaves through a slot in the roof. The roof itself keeps rain off the camera.
//
// Set to the Alpha Scents red plastic delta trap (hardware/TRAP.md). Its 110 mm peak is too low
// for this inside mount to see the whole card (lens 85 mm up sees ~113 mm of the 174 mm across);
// the lens needs to sit ~131-150 mm up, above the roof peak. Redesign as a roof housing before printing.
// Camera numbers follow the Raspberry Pi Camera Module 3 board (25 x 24 mm, M2 holes
// on a 21 x 12.5 mm pattern). Check them against the official mechanical drawing
// before printing.
// Not yet test-printed.

/* [Trap] */
floor_w = 195;      // mm, inside floor width
apex    = 110;      // mm, floor to inside apex
/* [Mount] */
mount_len   = 45;   // mm along the trap
drop        = 25;   // mm from the apex down to the camera face (matches --cam-drop); face must be >= 26 mm wide
wall        = 2.4;
/* [Camera Module 3] */
board_w = 25; board_h = 24; board_t = 1.2;
hole_dx = 21; hole_dy = 12.5; hole_d = 2.2; hole_top = 2;   // hole row 2 mm from the board's top edge
back_clear = 3.5;   // room for the connector/components on the back of the board

half = atan((floor_w / 2) / apex);          // roof panel angle from vertical
w_at_face = 2 * drop * tan(half);          // wedge width at the camera face

module wedge() {
    // Triangular prism matching the apex "V" down to the camera face, extruded along the trap.
    rotate([90, 0, 0]) linear_extrude(height = mount_len, center = true)
        polygon([[0, 0], [-w_at_face / 2, -drop], [w_at_face / 2, -drop]]);
}

module camera_pocket() {
    // Board pocket open to the bottom (lens points down), screw holes for M2 self-tappers
    // driven up through the board, and a channel that carries the ribbon to the apex slot.
    translate([0, 0, -drop]) {
        translate([-board_w / 2 - 0.3, -board_h / 2 - 0.3, -0.01]) cube([board_w + 0.6, board_h + 0.6, board_t + back_clear]);
        for (sx = [-1, 1], sy = [0, 1])
            translate([sx * hole_dx / 2, board_h / 2 - hole_top - sy * hole_dy, 0]) cylinder(d = hole_d - 0.4, h = 10, $fn = 24);
        // ribbon: along the pocket's back face to the end of the mount, then straight up to the apex
        translate([-8.5, board_h / 2 - 1, board_t]) cube([17, mount_len, 2.5]);
        translate([-8.5, mount_len / 2 - 3, board_t]) cube([17, 3, drop]);
    }
}

difference() {
    intersection() {
        wedge();
        // keep a solid shell even if the trap is very steep
        translate([-100, -mount_len / 2, -drop]) cube([200, mount_len, drop]);
    }
    camera_pocket();
}

echo(str("Roof half-angle ", half, " deg; wedge face ", w_at_face, " mm wide. The camera face must be >= 26 mm wide: increase drop if not."));

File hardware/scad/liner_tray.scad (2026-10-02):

// Orchard Sentinel: slide-in liner tray (the Sticky Pi "drawer" idea).
// Every fresh liner lands in exactly the same place under the camera.
// ArUco markers (hardware/print/tray_markers.png, 15 mm) sit in recessed pockets at
// the corners, OUTSIDE the liner, so alignment survives liner swaps.
// A small raised seat in the middle holds the lure in the spot the software masks out.
// Not yet test-printed. Large trays can be printed in two halves (split = true).

liner_w = 174;   // mm, Alpha Scents insert card across the trap (hardware/TRAP.md)
liner_l = 198;   // mm, along the trap
floor_w = 195;   // mm, trap floor the tray must fit on
floor_l = 227;   // mm, floor between the folded-up end flaps
clear   = 1.0;   // slack around the liner
rim     = 18;    // border that carries the markers
base_t  = 2.0;
lip_h   = 1.6;   // how far the rim stands above the liner bed
marker  = 15;    // ArUco size, mm
lure_w  = 24; lure_l = 12;   // lure seat footprint (matches the dashboard's default mask)
split   = false;

W = liner_w + 2 * (clear + rim);
L = liner_l + 2 * (clear + rim);

module tray() {
    difference() {
        cube([W, L, base_t + lip_h]);
        // liner bed
        translate([rim, rim, base_t]) cube([liner_w + 2 * clear, liner_l + 2 * clear, lip_h + 1]);
        // finger notch to lift the liner out
        translate([W / 2, rim - 1, base_t]) cylinder(d = 26, h = lip_h + 1, $fn = 48);
        // marker pockets, 0.4 mm deep, centred in the rim at each corner
        for (p = [[rim / 2, L - rim / 2], [W - rim / 2, L - rim / 2], [W - rim / 2, rim / 2], [rim / 2, rim / 2]])
            translate([p[0] - (marker + 1) / 2, p[1] - (marker + 1) / 2, base_t + lip_h - 0.4]) cube([marker + 1, marker + 1, 1]);
    }
    // lure seat: a low frame in the centre of the bed (the liner has a slit or the lure sits on top)
    translate([W / 2 - lure_w / 2 - 1.2, L / 2 - lure_l / 2 - 1.2, base_t])
        difference() {
            cube([lure_w + 2.4, lure_l + 2.4, 0.8]);
            translate([1.2, 1.2, -0.1]) cube([lure_w, lure_l, 1]);
        }
}

if (split) {
    intersection() { tray(); cube([W, L / 2, 10]); }
    translate([0, 10, 0]) intersection() { tray(); translate([0, L / 2, 0]) cube([W, L / 2, 10]); }
} else {
    tray();
}

if (W > floor_w || L > floor_l)
    echo(str("WARNING: tray ", W, " x ", L, " mm does not fit the ", floor_w, " x ", floor_l, " mm floor; shrink rim/marker."));
echo(str("Tray ", W, " x ", L, " mm. Mask for the dashboard (fractions of the image) is set per trap on the server."));

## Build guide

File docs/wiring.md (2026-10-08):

# Wiring: one trap unit

```
              Power (Option A, B or the 12 V build below)
                          │  battery +
                 INA219 (Vin+ → Vin−)  ── I2C ──┐
                          │                      │
                  5 V converter                  │
                          │ USB-C pigtail        │
                  ┌───────▼────────┐             │
                  │ Raspberry Pi 5  │◄────────────┘
                  │  CAM1 ── 500 mm ribbon ── Arducam UC-572, IMX219 wide-angle (in the apex mount)
                  │  J5 BAT ── RTC battery
                  │  GPIO17 ── MOSFET gate ── LED strip (−)
                  │  I2C ── SHT45 (in a small shield outside the box)
                  └─────────────────┘
```

## Power

Plan: **Option A** (DIY single-cell pack with solar). Backup: **Option B** (same pack, no panel, swapped at
each liner change), used if the charger side gives trouble or a trap hangs where the panel gets no sun.
The 12 V build is the off-the-shelf alternative.

Energy budget (estimates, Oct 2026, **not measured**; the full cycle has not run on a Pi yet): each photo
cycle is about 75 s at about 4.5 W, so ~0.15 Wh, or ~0.9 Wh a day at six photos. What sets battery life is
what draws power while the Pi is off (Pi off ~0.01 W, plus the converter and charger idling). With a
converter that idles under 1 mA, a trap needs **about 1.5–2 Wh a day**. Replace these numbers with the
INA219 log from a two-day bench run (see [bring-up.md](bring-up.md), "Before a trap goes out").

### Option A: DIY 1S pack with solar (plan)

```
 6 V 10 W panel ──► CN3791 solar charger board ──► 1S pack ── protection board
                    (TEMP pin ── 10 k NTC on the pack)          │
                                                           3 A inline fuse
                                                                │
                                                     INA219 ── 5 V ≥3 A boost ── Pi 5
```

| Part | Approx. cost (Oct 2026) | Notes |
|---|---|---|
| 6 V 10 W panel | $15–20 | On a post above the canopy, facing south, not in the tree beside the trap |
| CN3791 solar charger board | $3–6 | Sold in a 4.2 V (Li-ion) and a 3.6 V (LiFePO4) version: match the cells |
| 1S pack, ~40 Wh | $16–25 | 4 × 18650 in parallel, or 2 × 32700 LiFePO4. Salvaged laptop cells are fine after a capacity test; all cells in a pack the same type and charge |
| 1S protection board and cell holder | $3–5 | Low-voltage cut-off protects the cells when the panel can't keep up |
| 5 V boost converter, ≥3 A out | $5–10 | Measure its no-load current before using it: under ~1 mA. Not an MT3608 board (too small for a Pi 5) |
| 10 k NTC, fuse, wire | $3–5 | NTC to the CN3791 TEMP pin so it won't charge below 0 °C (April and October frosts) |
| INA219 | $5 | Already in the unit |
| **Total** | **~$50–75** | |

- About three weeks with no sun from a 40 Wh pack at ~2 Wh a day; a 10 W panel refills that in a day of sun.
- `battery_v` on the dashboard reads ~3.3–4.1 V (Li-ion) or ~3.0–3.5 V (LiFePO4) instead of ~13 V. The code
  has no voltage thresholds, so nothing else changes.
- On a 3.x V pack the boost draws up to ~3.5 A when the Pi is busiest. With the stock 0.1 Ω shunt the INA219
  reads at most 3.2 A, so peaks read low (the voltage is unaffected). To log the full current, fit a 0.05 Ω
  shunt and set `ina219_shunt_ohms = 0.05`.
- The Pi 5 should need only 1–2 A here (nothing on its USB ports), so a 3 A boost is enough;
  `PSU_MAX_CURRENT=5000` can stay.
- Keep the box shaded: 18650 cells should not sit above ~60 °C.

### Option B: battery swap, no solar (backup)

The Option A pack, boost, fuse and INA219 with the panel and charger board left out. The pack is sized for one
liner period (`SENTINEL_LINER_MAX_DAYS=28`): 28 days × ~2 Wh plus margin is ~65 Wh, so **6 × 18650 in parallel**.
Charge packs indoors with a 1S charger and swap one at every liner change. About **$30–40 per trap**, plus a
spare pack to rotate.

- A swap between two scheduled wakes looks like a power-button press. The server checks the photo before
  starting a new liner ([bring-up.md](bring-up.md), "Field mode"), so swap the battery and the liner together.
- **No off-the-shelf USB power bank.** Most turn themselves off once the Pi powers down and draws almost
  nothing, and then don't turn back on when the RTC alarm fires. The trap goes dead without any warning.
- Going from six photos a day to two (22:00 and 07:00) would stretch a pack by about a third.

### Off-the-shelf 12 V build

```
 20 W panel ──► ┌──────────────────────┐ ◄── LiFePO4 12.8 V 6 Ah
                │ Solar charge ctrl     │
                │ (LiFePO4 profile)     │
                └────── LOAD out ───────┘
                          │
                     3 A inline fuse
                          │
                 INA219 ── 12 → 5 V 5 A step-down ── Pi 5
```

About $200–280 per trap. The parts left on all day decide the battery life: a Genasun GV-5-Li (14.2 V
version, ~0.13 mA idle, $90–190) rather than a Victron SmartSolar 75/10 (~10 mA, $60–75) or a cheap PWM
controller, and a step-down that idles under ~1–2 mA. With typical parts the idle draw is 6–9 Wh a day, about
90% of the total. Buy a battery whose management board stops charging below 0 °C.

## Pi header

| Part | Pi 5 header pin | Notes |
|---|---|---|
| SHT45 VIN / GND | 1 (3V3) / 6 (GND) | STEMMA QT cable to a breakout; address 0x44 |
| SHT45 SDA / SCL | 3 (GPIO2) / 5 (GPIO3) | Shares the bus with the INA219 |
| INA219 VCC / GND / SDA / SCL | 17 (3V3) / 9 / 3 / 5 | Address 0x40; shunt 0.1 Ω (`ina219_shunt_ohms`) |
| LED MOSFET signal | 11 (GPIO17) | Logic-level MOSFET, low-side switch; common ground with the LED supply |
| LED supply | 5 V from the boost or step-down (or a 12 V strip from the controller load in the 12 V build) | Never power LEDs from the 3V3 pin |
| Camera | CAM/DISP 1 connector | Pi 5 uses the 22-pin *mini* connector: standard-to-mini cable. The Pi does not detect this board by itself: `camera_auto_detect=0` and `dtoverlay=imx219` in `/boot/firmware/config.txt` ([hardware/CAMERAS.md](../hardware/CAMERAS.md)) |
| RTC battery | J5 "BAT" | Keeps the clock through power loss; the wake alarm needs the RTC |

## Pi 5 EEPROM settings for the field

`sudo rpi-eeprom-config --edit` and add:

```
POWER_OFF_ON_HALT=1   # ~0.01 W when off, instead of ~1 W
WAKE_ON_GPIO=0        # needed so the RTC alarm is the wake source
PSU_MAX_CURRENT=5000  # stops the low-power warning; fine with a 3 A boost when nothing is on the USB ports
```

## Checks before closing the box

1. `i2cdetect -y 1` shows `40` (INA219) and `44` (SHT45).
2. `rpicam-still -o test.jpg` takes a photo. "No cameras available" means the `imx219` overlay above is missing.
3. Bench cycle (see bring-up.md) uploads a photo and the dashboard shows battery voltage.
4. RTC wake: `echo +120 | sudo tee /sys/class/rtc/rtc0/wakealarm && sudo halt`. The Pi should power back on about two minutes later.

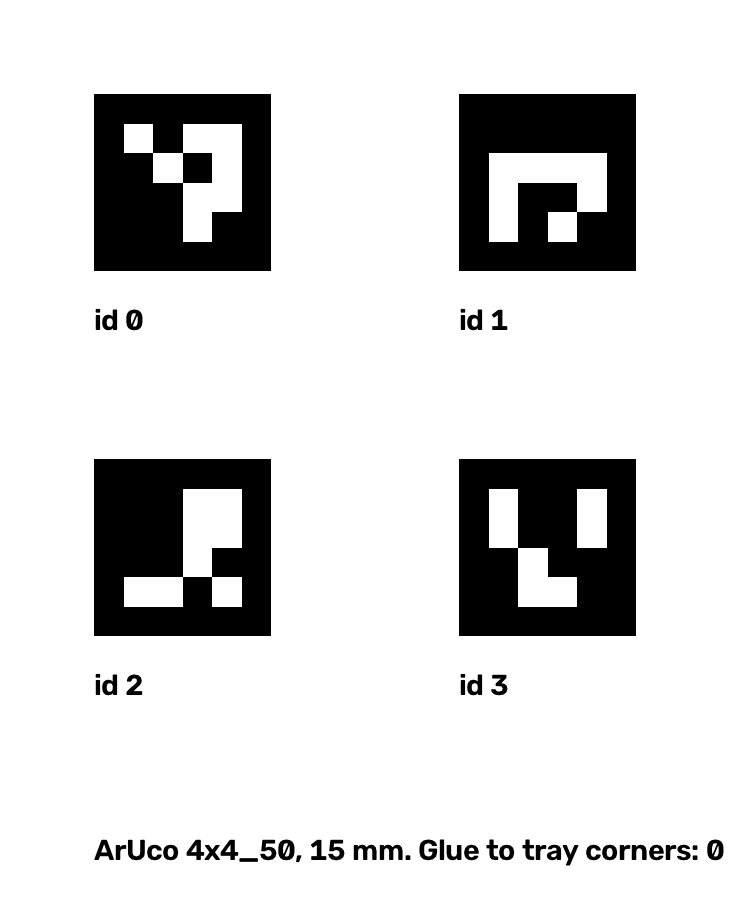
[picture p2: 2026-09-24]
hardware/print/tray_markers.png

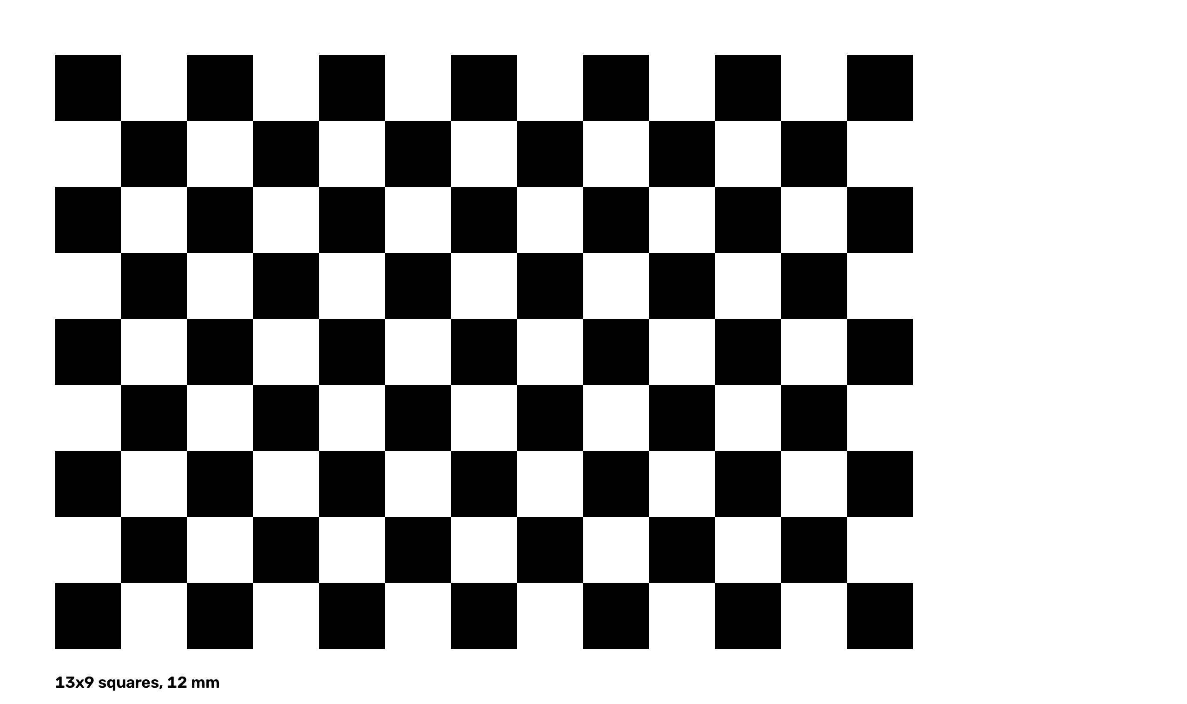
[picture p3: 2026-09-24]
hardware/print/checkerboard.png

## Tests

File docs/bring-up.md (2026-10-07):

# Bring-up: from a blank Pi 5 to photos on the dashboard

Do the server steps in [server-on-mac.md](server-on-mac.md) first, so there is somewhere to upload to.

## 1. Flash and first boot

1. Raspberry Pi Imager → **Raspberry Pi OS Lite (64-bit)**. In the settings: hostname `sentinel-t1`, your SSH public key, and the Wi-Fi network.
2. Boot, then `ssh pi@sentinel-t1.local` (or whatever user you set).
3. `sudo apt update && sudo apt full-upgrade -y && sudo reboot`
4. Camera check: `rpicam-still -o test.jpg --width 2304 --height 1296`. Copy `test.jpg` back and look at it.
   If it says no cameras are available with the wide-angle IMX219 (Arducam UC-572): the Pi doesn't detect that board by itself. Set `camera_auto_detect=0` and add `dtoverlay=imx219` in `/boot/firmware/config.txt`, then reboot.

## 2. Tailscale (lets the Pi reach the Mac from any network)

```bash
curl -fsSL https://tailscale.com/install.sh | sh
sudo tailscale up
```

Log in with the team's Tailscale account. `tailscale status` should list the Mac.

## 3. Install the trap software

```bash
git clone <your repo URL> sentinel && cd sentinel/device
sudo ./install.sh
```

On the Mac, create the trap and copy the key it prints:

```bash
sentinel-server add-trap T1 --lure CM --name "Bench mockup"
```

Edit `/etc/sentinel/config.toml` on the Pi: `trap_id`, `api_key`, and `server_url = "http://<mac's tailscale name>:8000"`.
For bench work, set `halt_after_cycle = false` and `manual_wake_is_new_card = false`.

## 4. Bench cycle

```bash
sudo -u sentinel /opt/sentinel/venv/bin/sentinel-cycle --config /etc/sentinel/config.toml --no-halt -v
```

The photo should appear on the dashboard within a few seconds. If the Mac is off, the photo waits in `/var/lib/sentinel/queue/` and goes up on the next run.

## 5. Tune the camera once, in the (mockup) trap

1. Put a liner with a few specimens (or the printed checkerboard) in the tray.
2. Focus. The wide-angle IMX219 (the current camera) has no focus motor: loosen the lens, turn it by hand until the grid lines and specimens are sharp at the card's distance, and fix it with a dab of glue or nail polish. Cameras with autofocus: `sudo -u sentinel /opt/sentinel/venv/bin/sentinel-focus-sweep --config /etc/sentinel/config.toml --out /tmp/focus`, then set `lens_position` to the best value it prints.
3. Light. The photo must be lit by the white LEDs, not by daylight through the red roof (that gives an all-red photo with almost no green or blue, and it changes with the weather). Line the inside of the roof with something opaque, and keep `exposure_us` short enough that the LEDs dominate.
4. Exposure, white balance and even lighting: swap the liner for a blank white card and run `sudo -u sentinel /opt/sentinel/venv/bin/sentinel-flatfield --config /etc/sentinel/config.toml`. It says whether `exposure_us` is too high or low (keep `analogue_gain` at 1.0 if possible) and prints the `colour_gains` to set; change them and run it again until it says both are fine. It also saves a white-card map (`flatfield.npz` in `data_dir`) that evens out every later photo, which removes the wide lens's green centre and pink edges (`lens_shading = false` switches off the stock correction that causes them). These values stay fixed for good; the model relies on every photo looking the same. Redo this step if the LEDs, camera or its height change.
5. Lens calibration: photograph `hardware/print/checkerboard.png` flat on the tray at ~10 positions/angles and keep the photos for the calibration script.

**USB webcam instead:** webcams have no manual exposure, and their auto-exposure clips the red
channel under an orange trap roof. Set `usb_controls` in `[camera]` (names from
`v4l2-ctl -d /dev/video0 --list-ctrls`); the Alcor Micro webcam in the orange Pherocon VI works with
`{ brightness = -40, saturation = 30, backlight_compensation = 0 }`. The capture also lowers
`brightness` by itself while more than `usb_max_clip_frac` of any channel is saturated, and reports
`brightness`/`clipped_frac` in the photo's metadata.

**Check detection on the bench** (on the Mac): copy a few photos over and run
`.venv/bin/sentinel-server detect photo1.jpg photo2.jpg --out overlays/`. It prints how many insects
it found and the grid it measured (spacing in px, angle, px/mm), and saves copies with boxes drawn.
Set the liner's grid spacing as `SENTINEL_GRID_MM` in `.env` (25 for the Alpha Scents card; measure others with a ruler): the
detector uses it to turn pixels into millimetres (it ignores anything under 3 mm or over 30 mm).
If the lure isn't in the photo, clear the default lure mask: `sentinel-server set-mask T1 --none`.
With a wide or fisheye lens the grid lines bend; the detector straightens the photo first (it tries
lens corrections until the grid lines are straightest, once per liner) and prints the `lens k` it used:
0 for a normal lens, around −0.2 for the wide lens we tried. If it guesses wrong on a nearly empty
or very crowded liner, fix it with `SENTINEL_LENS_K=-0.2` in `.env` (or try values with `detect --lens`).

## 6. Field mode

```bash
sudo rpi-eeprom-config --edit     # POWER_OFF_ON_HALT=1, WAKE_ON_GPIO=0, PSU_MAX_CURRENT=5000
sudo systemctl enable sentinel-cycle
```

In the config: `halt_after_cycle = true`, `manual_wake_is_new_card = true`. From then on, every boot runs one cycle and powers off until the next scheduled time. **After swapping a liner, press the Pi's power button**: the trap wakes, takes a baseline photo, and the server starts a new liner. The dashboard's "New liner installed" button does the same thing.

A boot counts as a button press only if it comes *before* the next scheduled wake and the last cycle powered the Pi off itself. A boot after a missed wake (flat battery, unplugged) or after a cycle that was cut short uploads its photo as `power_restored` or `interrupted` and keeps the current liner. Power that is removed and put back between two scheduled wakes, such as a quick battery swap, looks exactly like a button press to the Pi, so the server checks the photo before it believes one: if at least half of the insects counted on the old liner are still in the same places, it keeps the old liner and logs "new card ignored" under Recent events. An old liner with nothing counted on it gives the server nothing to compare, and a new liner starts (with nothing to count twice). If it ever keeps the old liner after a real change, press "New liner installed" on the dashboard; that button and `sentinel-cycle --new-card` are never second-guessed.

To stop the cycle and work on the Pi, SSH in during a wake and run `sudo systemctl disable sentinel-cycle`, or set `halt_after_cycle = false` from the server (next section).

## Before a trap goes out

The failures other groups report from the field are mundane, so check them on the bench first:

- [ ] Battery charged the day before, not taken from storage: run two full days of scheduled cycles on it and
      note the voltage drop per cycle (the dashboard shows `battery_v` for every photo).
- [ ] Every cable gland and the lid seal closed with no cable trapped in it; leave the closed box under a
      running tap or out in rain once and open it dry.
- [ ] The lure hangs where the camera does not see it, or inside the trap's mask (`sentinel-server set-mask`),
      and its shadow does not fall on the card under the LED.
- [ ] A fresh liner, white card calibration done for this camera, LED position and trap
      (`sentinel-flatfield`), and no `glare` event on the first photos.
- [ ] `sentinel-server detect` on a photo of the empty liner in the closed trap: the green card outline sits
      on the card's edge and nothing is boxed.
- [ ] An OFM-sized mark (6 mm) in a corner of the card measures at least 50 px in the photo.
- [ ] The Pi has uploaded with the lid closed from where the trap will hang (Wi-Fi or hotspot reach).
- [ ] Liner changes are in the calendar: at the latest every 28 days, sooner at `card_full` or `card_old`.

## Changing settings remotely

The server sends `device_config` for the trap in every upload reply (schedule, camera, LED). For now, edit it in the database or a Python shell. A settings page on the dashboard is a later task.

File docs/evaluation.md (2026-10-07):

# Measuring accuracy

`sentinel-server evaluate` compares what the pipeline counted with what a person counted. It
gives the report's three numbers, each with a pass mark:

| Result | How it's measured | Pass mark | Why |
|---|---|---|---|
| Count accuracy per liner | 1 − \|auto − manual\| / manual, per pest and for all moths | ≥ 0.80 | Suto (2022): no standard metric, but forecasting tolerates ~20% error |
| Count per trap-day | new moths that day, automatic vs manual: mean error, and days within 20% or one moth | report | a liner's total can be right while its days are wrong, and the biofix is made of days |
| Detection | a detection matches a drawn insect when IoMin = overlap / smaller box > 0.5 | report P / R / F1 | Ding & Taylor (2016); fairer than IoU for small insects in loose boxes |
| Detection by size | recall and species accuracy by the drawn insect's long side (under 30, 30–75, 75–150, over 150 px) | report | accuracy swings ~20 points between small and large crops (AMI dataset); an average hides the OFM |
| False moths by cause | every detection counted as a moth that is not one: bycatch, debris, or nothing there | report | Preti et al. (2021): up to 67% false positives in a codling moth trap, from scales, leaves, lure shadow and flies |
| Tracking | insects given more than one track (counted twice), tracks that took in more than one insect | report | most papers only check tracks by eye |
| Photos | share left out (blurred, scale or grid misread) and why; px/mm and the OFM's length in px (need ≥ 50); worst glare; oldest liner | report | ~7% of camera-trap photos were unusable in one study; resolution sets what can be told apart |
| Biofix | NEWA sustained-catch date from the manual count vs from the automatic count | within 1 day | the date growers actually act on |

It also reports what two-photo confirmation removes: detections seen in one photo and never
again, and what the count would be without confirmation (Preti et al.'s prototype over-counted
1.5–3× without it).

```bash
cd server
.venv/bin/sentinel-server evaluate                                   # confirmation stats, every liner
.venv/bin/sentinel-server evaluate --counts truth/counts.csv --boxes truth/boxes.csv --out eval.md
```

## Making the truth files

**`counts.csv`**: count each liner by hand (from the liner itself, not the photos), writing down
the day each insect first appeared. `card` is the liner's number on the dashboard: the trap page shows it as
"liner #3 installed …" (a new number each time the liner is changed).

```csv
card,date,label,count
3,2026-10-06,CM,2
3,2026-10-07,CM,1
3,2026-10-07,other_moth,1
```

Labels: `CM`, `OFM`, `OBLR`, `other_moth`, `other_insect`, `debris`. Days with nothing new need no row.

**`boxes.csv`** (optional, for the detection scores): draw a box around every insect on a few photos,
e.g. in any image viewer that shows pixel coordinates, or with a labelling tool that exports boxes.
Box every insect, also the tiny, blurred, half-hidden and decayed ones: leaving them out makes the
score look better than the count will be. Box debris too (leaf bits, loose scales, the lure) with the
label `debris`: it is not an insect to find, but it tells the report what a false moth was. To score
tracking, box the same liner on two or more days and give each insect a name in `insect` (anything,
as long as it is the same in every photo).

```csv
photo,x1,y1,x2,y2,label,insect
20261007T110000Z_T1.jpg,412,220,470,248,CM,a
20261008T110000Z_T1.jpg,413,221,470,249,CM,a
20261008T110000Z_T1.jpg,150,300,171,322,debris,
```

## What the locked test cards must include

The known failure modes, so the numbers mean something (from Suto 2022, Trapview, Preti et al.):

- **touching insects**: at least a few pairs placed wing to wing, end to end and crossed;
  the detector splits them or counts them by size and sends them to review;
- **look-alikes**: other tortricids, lesser appleworm, redbanded leafroller next to the targets;
- **debris**: leaf bits, twigs, seeds, insect parts, dust;
- **bycatch**: flies, small wasps, beetles (`other_insect`);
- **ageing**: leave some cards in for a week or more, since moths lose scales and change on the glue
  (wing patterns were badly degraded after ~72 h in a fall armyworm study);
- **the smallest target at the worst place**: OFM (6 mm) in the card's corners, where the wide lens
  gives 10–11 px/mm instead of 15;
- **the rim**: an insect within a few mm of the card's edge (the detector ignores the outer 4 mm);
- **spread wings**: a moth stuck with its wings open, which detectors count twice;
- **a full liner**: one card past 60 insects, where counts stop being trustworthy and the liner should
  have been changed.

Any change to the trap's colour, liner, light, camera or its height means new locked cards: results
measured before the change don't carry over.

Keep the locked cards out of training: list them in `ml/data/own/locked_test.txt` (see `ml/README.md`).

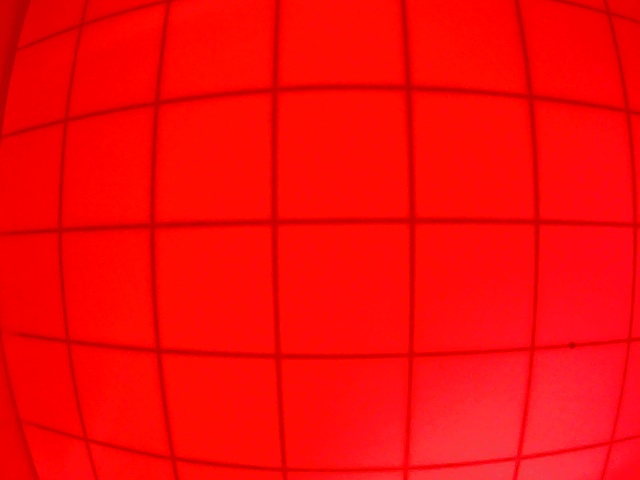
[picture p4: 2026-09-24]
server/tests/fixtures/empty_liner_wide.jpg

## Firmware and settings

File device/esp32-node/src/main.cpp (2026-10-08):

// ESP32-S3 camera trap: wake, photograph the liner, queue the photo in flash, upload the queue to the
// hub Pi, ask it when to wake next, deep-sleep. See device/esp32-node/README.md.
//
// Timekeeping: the node never sets its clock. `clock` is seconds since power-on, which keeps counting
// through deep sleep on the RTC timer, and `offset` (hub time - clock) is measured on every contact.
// Comparing successive offsets gives the RTC's drift, which shortens or lengthens the next sleep.
#include <Arduino.h>
#include <ArduinoJson.h>
#include <HTTPClient.h>
#include <LittleFS.h>
#include <Preferences.h>
#include <WiFi.h>
#include <algorithm>
#include <sys/time.h>
#include <vector>
#include "esp_camera.h"
#include "node_config.h"

#define FW_VERSION "0.1.0"
static const int CONNECT_MIN_S = 120;      // keep trying the hub at least this long per wake
static const int CONNECT_MAX_S = 300;
static const int UNSYNCED_SLEEP_S = 600;   // never heard from the hub: try again this often
static const size_t FS_RESERVE = 600000;   // drop the oldest photos to keep this much flash free
static const int MAX_WAKES = 12;

// Survives deep sleep, lost on power loss.
RTC_DATA_ATTR uint32_t session = 0;        // random per power-on: photos from an older session have no usable clock
RTC_DATA_ATTR bool synced = false;
RTC_DATA_ATTR double offset = 0;           // hub unix time - clock
RTC_DATA_ATTR double sync_clock = 0;       // clock at that measurement
RTC_DATA_ATTR double rate = 1.0;           // real seconds per clock second while asleep
RTC_DATA_ATTR int64_t wakes[MAX_WAKES];    // upcoming wake times (hub unix seconds)
RTC_DATA_ATTR int n_wakes = 0;
RTC_DATA_ATTR uint32_t boots = 0;
RTC_DATA_ATTR char last_error[96] = "";

static double clockNow() {
  struct timeval tv;
  gettimeofday(&tv, nullptr);
  return tv.tv_sec + tv.tv_usec / 1e6;
}

static void setError(const char *msg) {
  Serial.printf("ERROR %s\n", msg);
  strlcpy(last_error, msg, sizeof(last_error));
}

static String isoTime(double unix) {
  time_t t = (time_t)unix;
  struct tm tm;
  gmtime_r(&t, &tm);
  char buf[32];
  strftime(buf, sizeof(buf), "%Y-%m-%dT%H:%M:%S+00:00", &tm);
  return buf;
}

// ------------------------------------------------------------------ camera

static bool cameraInit() {
  camera_config_t c = {};
  c.pin_pwdn = -1; c.pin_reset = -1; c.pin_xclk = CAM_PIN_XCLK;
  c.pin_sccb_sda = CAM_PIN_SIOD; c.pin_sccb_scl = CAM_PIN_SIOC;
  c.pin_d7 = CAM_PIN_D7; c.pin_d6 = CAM_PIN_D6; c.pin_d5 = CAM_PIN_D5; c.pin_d4 = CAM_PIN_D4;
  c.pin_d3 = CAM_PIN_D3; c.pin_d2 = CAM_PIN_D2; c.pin_d1 = CAM_PIN_D1; c.pin_d0 = CAM_PIN_D0;
  c.pin_vsync = CAM_PIN_VSYNC; c.pin_href = CAM_PIN_HREF; c.pin_pclk = CAM_PIN_PCLK;
  c.xclk_freq_hz = 20000000; c.ledc_timer = LEDC_TIMER_0; c.ledc_channel = LEDC_CHANNEL_0;
  c.pixel_format = PIXFORMAT_JPEG; c.frame_size = CAM_FRAMESIZE; c.jpeg_quality = CAM_JPEG_QUALITY;
  c.fb_count = 2; c.fb_location = CAMERA_FB_IN_PSRAM; c.grab_mode = CAMERA_GRAB_LATEST;
  if (esp_camera_init(&c) != ESP_OK) return false;
  sensor_t *s = esp_camera_sensor_get();
  if (CAM_AEC_VALUE >= 0) { s->set_exposure_ctrl(s, 0); s->set_aec_value(s, CAM_AEC_VALUE); }
  if (CAM_AGC_GAIN >= 0) { s->set_gain_ctrl(s, 0); s->set_agc_gain(s, CAM_AGC_GAIN); }
  return true;
}

// Photograph the liner and queue it in flash as /q/<seq>-<id>.jpg + .json.
static bool captureToQueue(const char *wake_reason, bool new_card) {
  if (!cameraInit()) { setError("camera not found"); return false; }
  if (LED_PIN >= 0) { pinMode(LED_PIN, OUTPUT); digitalWrite(LED_PIN, HIGH); delay(LED_SETTLE_MS); }
  for (int i = 0; i < CAM_SETTLE_FRAMES; i++) { camera_fb_t *f = esp_camera_fb_get(); if (f) esp_camera_fb_return(f); }
  camera_fb_t *fb = esp_camera_fb_get();
  double taken = clockNow();
  if (LED_PIN >= 0) digitalWrite(LED_PIN, LOW);
  if (!fb) { setError("capture failed"); esp_camera_deinit(); return false; }

  sensor_t *s = esp_camera_sensor_get();
  JsonDocument meta;
  char id[17];
  snprintf(id, sizeof(id), "%08lx%08lx", (unsigned long)esp_random(), (unsigned long)esp_random());
  meta["node_capture_id"] = id;
  meta["clock"] = taken;
  meta["session"] = session;
  meta["wake_reason"] = wake_reason;
  meta["new_card"] = new_card;
  if (new_card) meta["new_card_source"] = "button";
  JsonObject cam = meta["camera"].to<JsonObject>();
  cam["sensor_pid"] = s->id.PID; cam["width"] = fb->width; cam["height"] = fb->height;
  cam["jpeg_quality"] = CAM_JPEG_QUALITY; cam["aec_value"] = CAM_AEC_VALUE; cam["agc_gain"] = CAM_AGC_GAIN;

  // Make room: oldest photos go first.
  std::vector<String> names;
  File dir = LittleFS.open("/q");
  for (File f = dir.openNextFile(); f; f = dir.openNextFile()) if (String(f.name()).endsWith(".jpg")) names.push_back(f.name());
  std::sort(names.begin(), names.end());
  for (size_t i = 0; i < names.size() && LittleFS.totalBytes() - LittleFS.usedBytes() < fb->len + FS_RESERVE; i++) {
    String stem = "/q/" + names[i].substring(0, names[i].length() - 4);
    LittleFS.remove(stem + ".jpg"); LittleFS.remove(stem + ".json");
    setError("flash full: dropped the oldest photo");
  }

  Preferences prefs;
  prefs.begin("node");
  uint32_t seq = prefs.getUInt("seq", 0) + 1;
  prefs.putUInt("seq", seq);
  prefs.end();
  char stem[40];
  snprintf(stem, sizeof(stem), "/q/%08lu-%s", (unsigned long)seq, id);
  File jpg = LittleFS.open(String(stem) + ".jpg", "w");
  bool ok = jpg && jpg.write(fb->buf, fb->len) == fb->len;
  jpg.close();
  File js = LittleFS.open(String(stem) + ".json", "w");
  ok = ok && js && serializeJson(meta, js) > 0;
  js.close();
  Serial.printf("captured %s %ux%u %u bytes\n", stem, fb->width, fb->height, fb->len);
  esp_camera_fb_return(fb);
  esp_camera_deinit();
  if (!ok) { LittleFS.remove(String(stem) + ".jpg"); setError("could not save photo"); }
  return ok;
}

// ------------------------------------------------------------------ hub

static bool connectWifi(int max_s) {
  WiFi.mode(WIFI_STA);
  WiFi.setSleep(false);
  uint32_t until = millis() + max_s * 1000UL;
  wl_status_t st = WL_IDLE_STATUS;
  while (millis() < until) {
    WiFi.begin(WIFI_SSID, WIFI_PASSWORD);
    for (int i = 0; i < 100 && (st = WiFi.status()) != WL_CONNECTED; i++) delay(100);
    if (st == WL_CONNECTED) {
      Serial.printf("wifi %s ip %s rssi %d\n", WIFI_SSID, WiFi.localIP().toString().c_str(), WiFi.RSSI());
      return true;
    }
    WiFi.disconnect();
    delay(3000);  // the hub may still be booting
  }
  // 1: SSID not seen, 4: refused (password, or a network that wants this MAC registered), 6: lost
  Serial.printf("wifi %s failed status %d mac %s\n", WIFI_SSID, st, WiFi.macAddress().c_str());
  return false;
}

// Everything the hub's reply says about time: measure the offset, update the drift, store the wakes.
static void takeTime(JsonDocument &reply, double sent_clock) {
  if (!reply["now"].is<double>()) return;
  double now_clock = clockNow();
  double new_offset = reply["now"].as<double>() - (sent_clock + now_clock) / 2;
  if (synced && now_clock - sync_clock > 3600) {
    // Over the last stretch the hub's time moved (now_clock - sync_clock) + (new_offset - offset) seconds.
    double r = ((now_clock - sync_clock) + (new_offset - offset)) / (now_clock - sync_clock);
    if (r > 0.9 && r < 1.1) rate = 0.7 * rate + 0.3 * r;
  }
  offset = new_offset; sync_clock = now_clock; synced = true;
  JsonArray w = reply["wakes"].as<JsonArray>();
  if (!w.isNull()) {
    n_wakes = 0;
    for (JsonVariant v : w) if (n_wakes < MAX_WAKES) wakes[n_wakes++] = v.as<int64_t>();
  }
}

static int post(const String &path, const char *method, File *body, const String &meta, JsonDocument &reply) {
  HTTPClient http;
  http.begin(String(HUB_URL) + path);
  http.setTimeout(20000);
  http.addHeader("Authorization", String("Bearer ") + API_KEY);
  if (meta.length()) http.addHeader("X-Sentinel-Meta", meta);
  double sent = clockNow();
  int code;
  if (body) { http.addHeader("Content-Type", "image/jpeg"); code = http.sendRequest(method, body, body->size()); }
  else code = http.sendRequest(method);
  if (code > 0) {
    if (!deserializeJson(reply, http.getString())) takeTime(reply, sent);
  }
  http.end();
  return code;
}

// Upload the queue oldest first. Returns 0 when it is empty, or the reply that stopped it
// (401: the hub does not know this key; anything else: the hub is not answering yet).
static int uploadQueue() {
  std::vector<String> names;
  File dir = LittleFS.open("/q");
  for (File f = dir.openNextFile(); f; f = dir.openNextFile()) if (String(f.name()).endsWith(".jpg")) names.push_back(f.name());
  std::sort(names.begin(), names.end());
  for (const String &name : names) {
    String stem = "/q/" + name.substring(0, name.length() - 4);
    File js = LittleFS.open(stem + ".json");
    JsonDocument meta;
    if (!js || deserializeJson(meta, js)) { js.close(); LittleFS.remove(stem + ".jpg"); LittleFS.remove(stem + ".json"); continue; }
    js.close();
    double clk = meta["clock"].as<double>();
    bool same_session = meta["session"].as<uint32_t>() == session;
    if (synced && same_session) {
      meta["clock_synced"] = true;
      meta["captured_at"] = isoTime(clk + offset);
    } else {
      meta["clock_synced"] = false;
      meta["age_s"] = same_session ? clockNow() - clk : 0;
      if (!same_session) meta["clock_lost"] = true;  // power was lost since: the hub dates it on arrival
    }
    meta["trap_id"] = TRAP_ID;
    JsonObject dev = meta["device"].to<JsonObject>();
    dev["sw_version"] = FW_VERSION; dev["rssi"] = WiFi.RSSI(); dev["boots"] = boots;
    dev["cpu_temp_c"] = temperatureRead(); dev["last_error"] = last_error[0] ? last_error : nullptr;
    dev["fs_free_kb"] = (LittleFS.totalBytes() - LittleFS.usedBytes()) / 1000;
    dev["drift_ppm"] = (rate - 1.0) * 1e6;
    String header;
    serializeJson(meta, header);

    File jpg = LittleFS.open(stem + ".jpg");
    JsonDocument reply;
    int code = post("/node/v1/captures", "POST", &jpg, header, reply);
    jpg.close();
    Serial.printf("upload %s -> %d\n", stem.c_str(), code);
    if (code == 200 || code == 201 || code == 413 || code == 415 || code == 422) {
      if (code >= 400) setError("hub refused a photo");
      LittleFS.remove(stem + ".jpg"); LittleFS.remove(stem + ".json");
      if (code < 400) last_error[0] = 0;
    } else {
      if (code == 401) setError("hub does not know this trap's key");
      return code == 0 ? -1 : code;
    }
  }
  return 0;
}

// ------------------------------------------------------------------ sleep

static void sleepUntilNextWake() {
  double now = clockNow();
  double sleep_clock = UNSYNCED_SLEEP_S;
  if (synced) {
    double hub_now = now + offset;
    for (int i = 0; i < n_wakes; i++) {
      double real = wakes[i] - hub_now;
      if (real < 60) continue;
      // Wake early by a margin that grows with the sleep, then convert hub seconds to RTC seconds.
      double margin = 15 + 0.003 * real;
      sleep_clock = (real - margin) / rate;
      break;
    }
  }
  if (sleep_clock < 30) sleep_clock = 30;
  Serial.printf("sleeping %.0f s\n", sleep_clock);
  Serial.flush();
  esp_sleep_enable_timer_wakeup((uint64_t)(sleep_clock * 1e6));
  if (BUTTON_PIN >= 0) esp_sleep_enable_ext0_wakeup((gpio_num_t)BUTTON_PIN, 0);
  esp_deep_sleep_start();
}

void setup() {
  Serial.begin(115200);
  boots++;
  esp_sleep_wakeup_cause_t cause = esp_sleep_get_wakeup_cause();
  if (session == 0) session = esp_random() | 1;
  const char *reason = cause == ESP_SLEEP_WAKEUP_TIMER ? "scheduled" : cause == ESP_SLEEP_WAKEUP_EXT0 ? "manual" : "first";
  bool new_card = cause == ESP_SLEEP_WAKEUP_EXT0;
  Serial.printf("\nsentinel node %s fw %s wake=%s boots=%lu synced=%d\n", TRAP_ID, FW_VERSION, reason, (unsigned long)boots, synced);

  if (!LittleFS.begin(true)) setError("flash filesystem failed");
  LittleFS.mkdir("/q");
  captureToQueue(reason, new_card);

  double real_margin = n_wakes ? 15 + 0.003 * 43200 : 0;  // as early as we might have woken
  int connect_s = std::min(CONNECT_MAX_S, CONNECT_MIN_S + (int)(2 * real_margin));
  uint32_t until = millis() + connect_s * 1000UL;
  if (connectWifi(connect_s)) {
    // The hub's Wi-Fi can be up before its gateway opens (it is still booting or photographing its
    // own liner), so keep trying it for the rest of this wake's window.
    int code = -1;
    while ((code = uploadQueue()) != 0 && code != 401 && (int32_t)(until - millis()) > 5000) {
      delay(5000);
      if (WiFi.status() != WL_CONNECTED) connectWifi(std::max(10, (int)((int32_t)(until - millis()) / 1000)));
    }
    if (code == 0) {
      JsonDocument reply;
      String status;
      JsonDocument st;
      st["last_error"] = last_error[0] ? last_error : nullptr;
      st["rssi"] = WiFi.RSSI();
      serializeJson(st, status);
      post("/node/v1/schedule", "GET", nullptr, status, reply);  // tells the hub this node is done
    } else if (code != 401) {
      setError("hub not answering");
    }
  } else {
    setError("hub not reachable");
  }
  WiFi.disconnect(true);
  WiFi.mode(WIFI_OFF);
  sleepUntilNextWake();
}

void loop() {}

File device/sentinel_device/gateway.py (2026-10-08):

"""Hub for ESP32 camera traps: take their photos over the orchard Wi-Fi and relay them to the server.

One Pi in the orchard is the hub. ESP32 traps in Wi-Fi range wake on the same schedule, photograph
their liner, POST the JPEG here, get back the time and how long to sleep, and deep-sleep again.
Each ESP32 is its own trap on the server with its own API key; the hub keeps a queue per trap
(data_dir/nodes/<trap_id>/) and uploads it with that trap's key, so the server needs no changes.

The cycle (cycle.py) keeps the gateway open for [hub] window_s each wake. On the bench, or to set up
a new ESP32, run it standalone and it stays open:

    sentinel-gateway --config config.toml --forward-every 60

Node protocol (all requests carry "Authorization: Bearer <that trap's server API key>"):

    POST /node/v1/captures   body: the JPEG; header X-Sentinel-Meta: JSON with node_capture_id
                             (random hex, the same on every retry), captured_at + clock_synced, or
                             age_s, new_card, camera, device
    GET  /node/v1/schedule   last call of a wake; marks the node done for this window

Both reply with {"now": unix seconds, "sleep_s": seconds until the node's next wake, "wakes": the next
12 wake times in unix seconds, ...}.
"""

from __future__ import annotations

import argparse
import hashlib
import json
import os
import logging
import re
import secrets
import sys
import threading
import time
from datetime import datetime, timedelta, timezone
from http.server import BaseHTTPRequestHandler, ThreadingHTTPServer
from pathlib import Path

import requests

from . import config as config_mod
from .schedule import next_wake
from .uploader import Queue, drain

log = logging.getLogger(__name__)

NODE_ID = re.compile(r"[0-9a-fA-F]{8,32}")
TRAP_ID = re.compile(r"[A-Za-z0-9][A-Za-z0-9_-]{0,31}")


def hash_key(key: str) -> str:
    """The server's key hash (sentinel_server.services.hash_key)."""
    return hashlib.sha256(key.encode()).hexdigest()


class Gateway:
    """Which ESP32 traps belong to this hub comes from the server (added and removed on the dashboard's
    "Set up traps" page) as {trap_id: key hash}, cached in data_dir/hub_nodes.json for wakes without
    a connection, plus any [hub.nodes.<trap_id>] in the config. A node's key arrives with its first
    request and is kept beside its queue (nodes/<trap_id>/key) to upload its photos."""

    def __init__(self, cfg: dict, data_dir: Path, clock=time.time):
        self.cfg = cfg
        self.hub = cfg["hub"]
        self.clock = clock
        data_dir.mkdir(parents=True, exist_ok=True)
        self.nodes_dir = data_dir / "nodes"
        self.cache = data_dir / "hub_nodes.json"
        self.local_keys: dict[str, str] = {}
        for trap_id, node in (self.hub.get("nodes") or {}).items():
            if not TRAP_ID.fullmatch(trap_id) or not node.get("api_key"):
                raise ValueError(f"[hub.nodes.{trap_id}] needs a plain trap id and an api_key")
            self.local_keys[trap_id] = node["api_key"]
        try:
            server = json.loads(self.cache.read_text())
        except (OSError, ValueError):
            server = {}
        self._set_nodes(server)
        self.done: set[str] = set()  # nodes that asked for their schedule since the window opened
        self.lock = threading.Lock()

    def _set_nodes(self, server: dict[str, str]) -> None:
        hashes = {t: h for t, h in server.items() if TRAP_ID.fullmatch(t) and isinstance(h, str)}
        hashes.update({t: hash_key(k) for t, k in self.local_keys.items()})
        self.hashes = hashes

    def refresh_nodes(self) -> bool:
        """Ask the server which ESP32 traps upload through this hub. Keeps the cached list if it can't."""
        try:
            r = requests.get(f"{self.cfg['server_url'].rstrip('/')}/api/v1/hub/nodes", timeout=5,
                             headers={"Authorization": f"Bearer {self.cfg['api_key']}"})
            r.raise_for_status()
            nodes = r.json()["nodes"]
            assert isinstance(nodes, dict)
        except (requests.RequestException, ValueError, KeyError, AssertionError) as e:
            log.warning("node list not refreshed (%s); using the last one: %s", e.__class__.__name__, ", ".join(self.hashes) or "none")
            return False
        tmp = self.cache.with_suffix(".tmp")
        tmp.write_text(json.dumps(nodes))
        os.replace(tmp, self.cache)
        before = set(self.hashes)
        self._set_nodes(nodes)
        if set(self.hashes) != before:
            log.info("nodes for this hub: %s", ", ".join(sorted(self.hashes)) or "none")
        return True

    def queue(self, trap_id: str) -> Queue:
        return Queue(self.nodes_dir / trap_id)

    def key_for(self, trap_id: str) -> str | None:
        if trap_id in self.local_keys:
            return self.local_keys[trap_id]
        try:
            return (self.nodes_dir / trap_id / "key").read_text().strip() or None
        except OSError:
            return None

    # ------------------------------------------------------------------ requests

    def trap_for(self, authorization: str) -> str | None:
        key = authorization.removeprefix("Bearer ").strip()
        if not key:
            return None
        given, found = hash_key(key), None
        for trap_id, h in self.hashes.items():  # compare against every hash so timing says nothing
            if secrets.compare_digest(given.encode(), h.encode()):
                found = trap_id
        if found and found not in self.local_keys and self.key_for(found) != key:
            path = self.nodes_dir / found / "key"
            path.parent.mkdir(parents=True, exist_ok=True)
            path.touch(mode=0o600)
            path.write_text(key)
        return found

    def schedule_reply(self) -> dict:
        now = datetime.fromtimestamp(self.clock(), timezone.utc)
        offset = timedelta(seconds=self.hub["node_offset_s"])
        # The node wakes node_offset_s after the hub's slot, once the hub has booted and opened the window.
        wakes, t = [], now - offset
        for _ in range(12):  # a node that misses a window still knows when to wake after that
            t = next_wake(t, self.cfg["schedule"]["times"], self.cfg["timezone"], min_gap=timedelta(minutes=2))
            wakes.append(t + offset)
        return {"now": now.timestamp(), "next_wake": wakes[0].isoformat(), "sleep_s": round((wakes[0] - now).total_seconds()),
                "wakes": [round(w.timestamp()) for w in wakes]}
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

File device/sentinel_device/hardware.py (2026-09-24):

"""LED switch and I2C sensors. Every function degrades to a no-op/None off the Pi."""

from __future__ import annotations

import logging
import time
from contextlib import contextmanager
from pathlib import Path

log = logging.getLogger(__name__)


@contextmanager
def led(enabled: bool, gpio: int):
    """Turn the liner LEDs on for the duration of the block."""
    device = None
    if enabled:
        try:
            from gpiozero import OutputDevice  # type: ignore

            device = OutputDevice(gpio, active_high=True, initial_value=False)
            device.on()
        except Exception as e:  # not on a Pi, or GPIO busy
            log.warning("LED control unavailable: %s", e)
            device = None
    try:
        yield
    finally:
        if device is not None:
            device.off()
            device.close()


def _crc8_sht(data: bytes) -> int:
    crc = 0xFF
    for byte in data:
        crc ^= byte
        for _ in range(8):
            crc = ((crc << 1) ^ 0x31) & 0xFF if crc & 0x80 else (crc << 1) & 0xFF
    return crc


def sht4x_decode(raw: bytes) -> tuple[float, float]:
    """Decode a 6-byte SHT4x high-precision reading into (°C, %RH). Raises on CRC failure."""
    if len(raw) != 6 or _crc8_sht(raw[0:2]) != raw[2] or _crc8_sht(raw[3:5]) != raw[5]:
        raise ValueError("SHT4x CRC mismatch")
    t_ticks = raw[0] << 8 | raw[1]
    rh_ticks = raw[3] << 8 | raw[4]
    temp_c = -45 + 175 * t_ticks / 65535
    rh = min(100.0, max(0.0, -6 + 125 * rh_ticks / 65535))
    return round(temp_c, 2), round(rh, 1)


def read_sht4x(bus_no: int = 1, address: int = 0x44) -> dict | None:
    try:
        from smbus2 import SMBus, i2c_msg

        with SMBus(bus_no) as bus:
            bus.i2c_rdwr(i2c_msg.write(address, [0xFD]))  # measure, high precision
            time.sleep(0.01)
            msg = i2c_msg.read(address, 6)
            bus.i2c_rdwr(msg)
            temp_c, rh = sht4x_decode(bytes(list(msg)))
        return {"temp_c": temp_c, "rh": rh}
    except Exception as e:
        log.warning("SHT4x read failed: %s", e)
        return None


def read_ina219(shunt_ohms: float, bus_no: int = 1, address: int = 0x40) -> dict | None:
    """Battery-side bus voltage and current from an INA219 (no calibration register needed)."""
    try:
        from smbus2 import SMBus

        with SMBus(bus_no) as bus:
            def reg(r: int) -> int:
                hi, lo = bus.read_i2c_block_data(address, r, 2)
                return hi << 8 | lo

            bus_v = (reg(0x02) >> 3) * 0.004
            shunt = reg(0x01)
            if shunt & 0x8000:
                shunt -= 1 << 16
            current_ma = shunt * 0.01 / shunt_ohms  # 10 µV per LSB -> mV / Ω = mA
        return {"battery_v": round(bus_v, 3), "current_ma": round(current_ma, 1)}
    except Exception as e:
        log.warning("INA219 read failed: %s", e)
        return None


def cpu_temp_c() -> float | None:
    p = Path("/sys/class/thermal/thermal_zone0/temp")
    try:
        return round(int(p.read_text()) / 1000, 1)
    except Exception:
        return None


def uptime_s() -> float | None:
    try:
        return float(Path("/proc/uptime").read_text().split()[0])
    except Exception:
        return None


RTC_WAKEALARM = Path("/sys/class/rtc/rtc0/wakealarm")


def set_rtc_wake(epoch_s: int) -> bool:
    """Program the Pi 5 RTC to power the board back on at epoch_s (UTC seconds)."""
    try:
        RTC_WAKEALARM.write_text("0")  # clear any pending alarm first
        RTC_WAKEALARM.write_text(str(int(epoch_s)))
        return True
    except Exception as e:
        log.error("could not set RTC wake alarm: %s", e)
        return False

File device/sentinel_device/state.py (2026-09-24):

"""Small JSON state file that survives shutdowns (last config from server, expected wake)."""

from __future__ import annotations

import json
import os
from pathlib import Path


class State:
    def __init__(self, data_dir: Path):
        self.path = data_dir / "state.json"
        self.data: dict = {}
        if self.path.exists():
            try:
                self.data = json.loads(self.path.read_text())
            except json.JSONDecodeError:
                self.data = {}

    def get(self, key, default=None):
        return self.data.get(key, default)

    def set(self, key, value) -> None:
        self.data[key] = value

    def save(self) -> None:
        tmp = self.path.with_suffix(".tmp")
        tmp.write_text(json.dumps(self.data, indent=2, sort_keys=True))
        os.replace(tmp, self.path)

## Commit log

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2026-09-24 Add USB webcam camera backend; fix .env inline comments
    The team's first Pi has a UVC webcam (Alcor Micro, 640x480) instead of the
    Camera Module 3, so add a 'usb' backend via OpenCV for bench testing.
    The server's .env loader kept inline comments as part of values, which
    created a data dir named 'data # database + photos...'. Strip them.
    [camera.py, config.py]
2026-09-24 Fix OFM degree-day milestones: count from biofix per UC IPM model
    The only OFM milestone (2nd flight, 1000-1400 DD) is measured from Jan 1,
    but the dashboard compares milestones to DD since biofix, so it would fire
    weeks late. Use the UC IPM stages from biofix (Croft 1980, Rice 1984):
    egg laying 50, egg hatch 200, next flight 965 DD base 45 F. Keep the
    Jan-1 2nd-flight window next to the Jan-1 total on the trap page.
2026-09-24 Add camera bench test for comparing candidate trap cameras
    sentinel-camera-bench shoots (USB webcam on Mac/Pi, or Pi camera) or scores any
    photo of the printed checkerboard, and reports px/mm, pixels across an OFM,
    edge blur in mm, contrast/noise and field of view; compare prints a table.
    [camera_bench.py]
2026-09-24 Get CV working on the real trap view: webcam exposure fix, grid-aware detector
    The USB webcam in the orange Pherocon VI clipped the red channel (95% of
    pixels at 255). Device: v4l2 controls from config (usb_controls) plus a clip
    guard that lowers brightness until no channel is saturated.
    Detector baseline-cv-0.2: darkness on each pixel's brightest channel (robust to
    the orange cast), vignetting divided out, liner grid found by projection (angle
    + spacing, which gives px/mm), grid lines removed with oriented openings over a
    fan of angles (perspective), blobs kept by size in mm. On real frames: 0 false
    positives on the empty liner, all synthetic moths found incl. on lines and at
    the edge. Fix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
    [camera.py, config.py]
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2026-09-24 Detector: correct wide/fisheye lens distortion; use clipped channels for the grid
    On the wide-lens liner photos the grid lines bend, so the grid wasn't found
    (fallback scale) and bent line pieces were counted as 10 insects on an empty
    liner. Two fixes:
    - find_grid only skipped a colour channel when 20% of it was clipped; under
    the red trap light the grid shows best in exactly that channel. Now only
    skipped when >90% clipped.
    - baseline-cv-0.3 straightens the photo with a one-parameter radial model.
    k is estimated by trying corrections until the grid is straightest
    (find_grid score), once per liner (cached by trap+card in the worker),
    and boxes are mapped back to the original photo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
2026-09-24 Count touching insects: split clumps at their necks, else count by area and send to review
    - detect: distance-transform watershed splits touching insects; unsplittable blobs that are
    dented, too wide or too long for one moth get Box.n = estimated count
    - detect: grid-line removal keeps structures much wider than the printed lines (measured
    per photo), so moths lying end to end along a line aren't erased; crossings still removed
    - n_insects on detections and tracks (auto-added to existing databases); counts, biofix
    catch dates and the review queue use it; reviewers can correct the count
2026-09-24 train_v1: save embeddings every ~2,000 photos so a stalled GPU doesn't lose the run
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2026-10-01 Device: always set the wake alarm and power off; keep photos queued on auth/URL errors
    - Any error in capture or upload (no camera, bad settings from the server) is logged and
    reported, and the cycle still sets the RTC alarm and halts. A broken remote schedule falls
    back to the local config, then the defaults.
    - Uploads stop starting after 180 s so systemd's 300 s timeout can't kill the cycle mid-way.
    - Only 400/413/415/422 park a photo; 401/403/404/5xx leave it queued for the next wake.
    [cycle.py, uploader.py]
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2026-10-02 ML: label photos of used field cards; per-insect grid scale
    crop_field_cards.py runs flatbug on phone photos of real liners and writes a crop, an RGBA cutout
    and a numbered overview per insect, plus data/field/labels.csv. px/mm comes from the card's printed
    grid around each insect (the value most patch sizes agree on, so a tilted card and close-ups both
    work; spacings shorter than the insect are glue texture and are ignored).
    label_field_cards.py is a local labelling page (stdlib server + one HTML page): pass 1 moth /
    other_insect / debris, delete, draw missed insects, resize and move boxes, undo/redo; pass 2
    species. labels.csv keeps flatbug's misses (manual), false hits (skip) and fixed b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
2026-10-02 ML: train on insects and debris from field cards
    crop_field_cards.py --cutouts outlines labelled boxes that have no flatbug outline (drawn by hand
    or resized): flatbug again on the box's neighbourhood, else the object separated from the white
    card by colour, with the printed grid's straight lines removed unless nothing else is left.
    make_trap_style.py --field pastes the field cutouts (other_insect and debris for now; moths once
    they have species) onto the liners at their measured length, skipping the cards held out in
    data/field/test_cards.txt. Each photo is named field_* and made from a generator seeded by its
    name, so re-runs write identical files: train_v1 caches embeddings by path. A fu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
2026-10-02 Labeller: drag pans, draw mode for boxes, trackpad pinch/scroll
    Drag (or two-finger scroll, arrow keys) pans; pinch, wheel or double-click
    zooms at the cursor, + / - zoom, F or 0 fits, with zoom limits. Drawing a
    box is now B (or the Draw box button) then drag, or Shift+drag, so panning
    no longer makes stray boxes. A plain click still selects.
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2026-10-06 Device: wide-angle IMX219 camera support and white-card calibration
    The trap camera is now the Arducam UC-572 (IMX219, 8 MP, fisheye lens).
    - Picamera2Camera only sets focus controls on cameras that have a focus
    motor, and reports the real sensor name instead of imx708_wide.
    - lens_shading = false drops the sensor's stock lens correction, which
    gives a green centre and pink edges under a wide-angle lens.
    - sentinel-flatfield photographs a blank white card, advises on
    exposure_us and colour_gains, and saves a gain map that evens out
    colour and lighting in every later photo (flat_field = true).
    - Config example, bring-up steps and hardware/CAMERAS.md updated.
    The flat-field maths is t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
    [camera.py, config.py, flatfield.py]
2026-10-06 Device: fixes from calibrating the IMX219 on a Pi; calibrated settings
    Running sentinel-flatfield on a Pi 5 with the wide-angle IMX219 found:
    - A second capture in the same process found no cameras: Picamera2
    leaves LIBCAMERA_RPI_TUNING_FILE pointing at a deleted temp file after
    a custom tuning. Clear it before each capture.
    - The red trap walls around the card wanted 4x green/blue gains, which
    smeared a cyan halo into the card's edges. The flat field now carries
    the card's gains outwards over anything that isn't white card.
    config.example.toml and CAMERAS.md record the values the calibration
    settled on in the red trap with the bench LED.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
    [camera.py, flatfield.py]
2026-10-06 Docs: IMX219 driver loading, first detector results, where the reference photos are
    The Pi doesn't auto-detect the Arducam UC-572; record the config.txt
    lines a trap Pi needs. Note what the detector does on a calibrated photo
    of an empty liner (15.3 px/mm, lens k -0.35, false detections only on the
    trap walls at the card's border) and where the 2026-10-06 reference
    photo set is kept.
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2026-10-06 Device: a boot after a power cut no longer starts a new liner
    Any boot off the schedule used to count as a power-button press. Now only a
    boot before the next scheduled wake, after a cycle that powered off by itself,
    does. A boot after a missed wake is power_restored, one after a cycle that was
    cut short is interrupted, and both keep the current liner. Power removed and
    restored between two wakes still reads as a press; bring-up.md says so.
    [cycle.py, schedule.py]
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2026-10-06 Server: a battery swap is not a new liner
    The Pi cannot tell its power button from power being pulled and put back
    between two wakes, so both arrive as a new liner. The worker now checks the
    photo that opened a liner that way against the liner before it: if at least
    half of the insects counted there are still in place, the new liner is undone
    and its photos join the old one (event: new_card_ignored). The dashboard
    button and sentinel-cycle --new-card (new_card_source = flag) are not checked.
    [cycle.py, schedule.py]
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2026-10-07 Docs: audited CV status, research findings applied item by item
    READMEs corrected against the run outputs. New docs/cv-research-status.md and
    docs/ml-research-status.md list every research finding with what was done and
    what could not be. Evaluation, server, bring-up and camera notes updated.
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2026-10-08 Docs: wiring power options, DIY 1S solar as the plan and battery swap as the backup
    Energy budget estimate, parts and Oct 2026 costs for each; the 12 V build kept as the off-the-shelf option.
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2026-10-08 Device: Pi hub gateway for ESP32 camera traps, and the ESP32 trap firmware
    The hub takes photos from ESP32-S3 camera traps in Wi-Fi range during each wake, gets
    its list of cameras from the server, and uploads each one's photos with that camera's key.
    The firmware queues photos in flash, keeps time against the hub and corrects for clock drift.
    [partitions.csv]
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2026-10-08 Device: ESP32 node keeps trying the hub for its whole window; bench run over RedRover
    The node now retries the hub's gateway every 5 s until its connect window ends instead of
    sleeping after the first refused upload, and prints its IP, RSSI, or Wi-Fi failure status and MAC.
    The standalone gateway refuses a config without an api_key. Docs: the Oct 8 bench run (ESP32 on
    RedRover -> gateway on the bench Pi -> server on the Mac over Tailscale) and how to repeat it.
    [gateway.py, main.cpp]
2026-10-10 Docs: bring the READMEs up to date, with known problems from the audit
    - README: ESP32 status includes the Oct 8 bench run over RedRover; the
    fake-camera end-to-end result re-run on Oct 10 (it no longer matches);
    a dated list of known problems found in the audit.
    - hardware/README: list CAMERAS.md; the mount is sized for the Camera
    Module 3, not the IMX219 board in use.
    - esp32-node/README: explain "ERROR hub not answering".
    - CAMERAS.md: px/mm was measured on the bench, not untested.
2026-10-10 Server: season biofix, worker survives failed saves, late photos on the right liner
    - The biofix comes from the current season's catches only, so last year's
    catches no longer start this year's degree-day clock.
    - A failed save (e.g. "database is locked") marks the capture failed in a
    fresh session instead of ending the worker thread; a failed pass is
    logged and retried.
    - An upload goes on the liner that was in the trap when the photo was
    taken, and a stale "new liner" flag does not open a liner. A photo that
    arrives after later photos of its liner were processed has the liner
    re-run in order.
2026-10-10 Server: grid finder settles on one spacing instead of averaging two
    When the two line families give different spacings (one profile locked
    onto a multiple), the spacing both repeat at most strongly, against half
    of it, is used. Fixes the fake camera's liner reading 6.9-29 px/mm (true
    11.6). On our 33 IMX219 photos the same 11 read right as before; the
    photos whose reading changed were wrong before and after.
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2026-10-22 Server: a hub's page shows its check-in and its cameras
    /traps/<hub> rendered the camera trap page, which needs a last photo, and a hub never has one, so it
    failed with a 500. A hub now gets its own page: when it last checked in and the cameras that use it.
    The overview's Hubs card links there. The test opens every page for a hub before and after it checks in.
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2026-10-22 Device: ESP32 reports awake time per wake; hub keeps node statuses
    Firmware 0.2.1: the end-of-wake status gives the wake type, how long it has been awake, the previous
    wake's whole awake time and whether it reached the hub, chip temperature and clock drift, for
    estimating power over a day. The gateway appends each status to nodes/<trap_id>/status.jsonl.
2026-10-22 Docs: field test kit for a day with the ESP32 on a window
    field-tests/esp32-window-day/: start.sh (pre-flight health on both Pis, the hub's address, the test
    schedule with a backup of the hub's config, 10-minute loggers, the camera's starting point), check.sh,
    event.sh (server and gateway outages, hub reboot, Take a photo now, notes), finish.sh (journals, logger
    CSVs, camera statuses, the server's rows and photos; puts the hub back) and report.py (reliability per
    slot, wake timing for drift, delay per hop, rssi and heat, boots, duplicates, statuses, power estimate,
    photos through the day). Separate from the regular code; run output goes to runs/ (gitignored).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
2026-10-22 Docs: window field test counts slots from the camera's first contact
    Until its first contact after start.sh the camera doesn't know the test schedule, so earlier slots
    aren't misses.
2026-10-22 Server: re-running a liner classifies before writing, so uploads aren't locked out
    PR #15 has the worker re-run a whole liner when a photo arrives after later
    ones, and reprocess_card deleted its detections and then classified every
    photo inside one write transaction: on the Pi 5 with BioCLIP on CPU that
    locked uploads out for minutes, the problem PR #17 fixed for single photos.
    Every photo is now detected and classified first, then written in one go.
    The window field test's report counts the firmware's new 'search' wakes
    (Wi-Fi only) at check-in current, not photo current.
2026-10-22 Device: ESP32 uploads on a fresh Wi-Fi connection after the setup preview
    After the 5-minute setup preview every upload to the hub failed for the
    rest of the wake while Wi-Fi still read as connected (twice on Oct 22 2026
    over RedRover, firmware 0.2.1 and 0.2.2), so the setup photo waited for the
    next wake. The node now drops Wi-Fi after the preview and connects afresh,
    and on any wake reconnects after every third failed upload instead of
    retrying one connection for the whole window. Firmware 0.2.3.
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2026-10-23 Server: dashboard's Error status says why on hover and links to the photo
    Hovering Error shows the reason (the newest photo's error, or what the camera
    reported); clicking it opens that photo, or the trap's page for a camera error.
    One status pill macro for the overview, trap, hub and manage pages.
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2026-10-23 Server: biofix review test pins its date so its catch weeks don't split
    The fixture put catches 12/11 and 5/4 days before now. NEWA weeks run Monday-Sunday,
    so on a Thursday or Friday each pair straddled a Monday, no week had two catches and
    there was no biofix. It would also have failed in early January, where the season
    filter drops last year's catches. Pin now to a Wednesday in June.
2026-10-24 Docs: review ledger of checked Gemini findings, with the unchecked ones kept apart
    code-review/LEDGER.md lists what Claude checked against the code, the live
    system (Oct 24 2026 snapshot) and the sources: 38 to-dos with evidence, known
    facts, and claims that turned out wrong. UNVERIFIED.md holds the ~290 Gemini
    claims not checked yet. build_ledger.py renders both as the ledger page;
    make_unverified.py regenerates the unverified list from gemini-raw/.
    Also keeps the Gemini brief and the read-only live-snapshot scripts.
2026-10-24 Docs: ledger marks L-02 and L-06 fixed and says how to work from it
    PRs #27 and #28 fixed the grid-finder crash and the date-dependent biofix
    test. The new top section tells the session doing the fixes the order, one
    PR per fix with a failing test first, to use the ledger's corrected fixes
    rather than Gemini's, and to leave the Unverified list alone until checked.
2026-10-24 Server: check photo scale against the camera's measured px/mm
    A liner's first photos set the scale every later photo was checked
    against, so when they misread the grid (T2: about a third of the true
    10.3 px/mm) every right photo after them was rejected. Traps now carry
    the camera's measured px/mm (`sentinel-server set-scale T2 10.3`); when
    it is set, every photo is checked against it, first photos included.
    Without it the old per-liner check stays.
    The grid finder also records which fraction of a measured spacing it
    chose, and a scale rejection says so, to test the 1/3 lead in L-01.
    Fixes L-01 (clamp part; ArUco tray left for later).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
2026-10-24 Device: measure ESP32 clock drift over an hour, not since the last contact
    The rate only updated after more than an hour since the last hub
    contact, and nodes check in every 10-30 min, so it never ran: drift_ppm
    was 0 in all 255 camera reports. The rate is now measured from a
    reference contact (clock and offset together) that moves only when the
    rate is updated (drift.h). Firmware 0.2.6.
    Fixes L-04.
2026-10-24 Server: nightly backup of the database and photos to another machine
    `sentinel-server backup DEST [--keep 14] [--push TARGET]` snapshots the
    database with SQLite's backup API, copies new photos beside it, prunes
    old snapshots, and rsyncs the folder to another machine (nothing is
    deleted there). sentinel-backup.{service,timer} run it at 03:30;
    docs/server-on-linux.md has setup and restore.
    Fixes L-05.
2026-10-24 ML: fix train_v1.py --final crash (text embeddings overwritten by T)
    The fitted temperature reused the name T, so the locked-card zero-shot
    line ran X @ T.T on a float and crashed. The text embeddings are now
    `text`. New test runs main(--final) on fake embeddings (skipped without
    scikit-learn, as in CI).
    Fixes L-07.
2026-10-24 Server: reprocessing no longer inflates or drops reviewed insects
    Reviewed tracks survive a reprocess, but kept their n_seen, misses,
    prob_sum and n_classified, so the replay counted on top of them. And
    the replay counted misses for photos taken before the insect landed,
    which dropped a reviewed candidate (and a fresh track then counted the
    same insect again). Kept tracks now start their counters over, and
    photos before first_seen_at aren't misses.
    Fixes L-10.
2026-10-24 Server: count liner age after the false-new-liner check
    The age (and the glare and card_old events) came from the photo's card
    before _keep_liner_if_unchanged could fold a battery-swap "new liner"
    back into the one before, so such a photo read 0 days and an old liner
    raised no card_old warning. The check now runs first.
    Fixes L-11.
2026-10-24 Server: a person can confirm or change a trap's biofix
    The trap page has a date field to confirm the biofix from the catches
    or set another date, and a button to go back to the catches. The date
    (Trap.biofix_date) counts for its own season only; the page says when
    the biofix is a person's and what the catches alone would give.
    Fixes L-13.
2026-10-24 Server: overview shows hubs before any camera is added
    The hub table sat inside {% if rows %}, so a fresh install with a hub
    and no cameras couldn't show whether the hub was checking in. The
    rows block now closes before the hub table and reopens after it, so
    the page order is unchanged when there are cameras.
    Fixes L-14.
2026-10-24 Device: a requested photo answers the request even from a clock behind
    The hub marked a dashboard photo request answered only by a photo
    taken after it. A node whose clock runs behind sent its "requested"
    photo with an earlier time, was told photo_now again, and kept taking
    photos. A photo with wake_reason "requested" now answers it too.
    Fixes L-15.
2026-10-24 Device: hub no longer skips a camera's photo after a late check-in
    Replies to cameras used the hub's own 2-minute boot margin, so a
    check-in at 09:59:10 was told "next wake 14:01" and the 10:01 photo
    was skipped. Cameras now get any wake at least 60 s away, the floor
    the firmware applies itself (untilNextWake).
    Fixes L-35.
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2026-10-24 Device: cap Wi-Fi time on photo wakes while the hub is down
    Every photo wake kept Wi-Fi on for up to 5 min looking for the hub
    (min(300, 120 + 2 x 144.6 s)). After a photo wake that can't reach the
    hub, the next ones now try for 45 s until the hub answers again; a
    successful check-in resets it.
    Fixes L-36.
2026-10-24 Server: threaded upload tests report a failed wait, not UnboundLocalError
    In both "upload commits while ..." tests, a failed wait for the slow
    classifier left `up` unassigned, and the finally block's up.join()
    raised UnboundLocalError over the real failure. `up` now starts as None.
    Fixes L-37.
2026-10-24 Server: keep the lure per liner, so a lure change doesn't rewrite the past
    Catches were read against the trap's current lure, so changing it
    reinterpreted every earlier liner (OFM bycatch on an old CM liner then
    counted towards the OFM biofix). Each liner now records its lure
    (Card.lure, filled from the trap on startup for existing liners), the
    biofix and evaluate read catches against it, and "New liner installed"
    can change the lure that goes in with the liner.
    Fixes L-16.
2026-10-24 Server: upload endpoint runs off the event loop, with a size cap
    upload_capture was `async def` doing blocking database and file work,
    so every other request waited while an upload was saved. It is a plain
    def now (run in FastAPI's thread pool) and reads the file with
    image.file.read(). Uploads over SENTINEL_MAX_UPLOAD_MB (default 25)
    get 413; only the hub capped size before.
    Fixes L-17.
2026-10-24 Docs: warn not to run install.sh on the bench Pi in bring-up.md
    bring-up.md step 3 says to run device/install.sh, which CLAUDE.md
    forbids on apple-pi-hub (the bench Pi this guide used to set up, now
    the shared hub). A note above the command says so.
    Fixes L-19.
2026-10-24 Docs: ledger marks the P0 and P1 code rows in review (PRs #31-#48)
    Each fixed row names its PR and what to do after merging. L-03, L-08
    and L-09 stay open with what to measure or run (board, cooler, bench
    Pi). The OBLR biofix question is answered (sustained), and step 7 now
    says how to mark a row whose PR is still open.
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2026-10-25 Server: dashboard leads with what to do this week, in a grower's words (#50)
    The overview opens on one row per trap saying what is due and when
    ("First spray in about 2 days", "Waiting for biofix"), with a degree-day
    track to the next milestone, then a "Needs a look" list (offline trap,
    failed photo, old liner, insects to confirm) in place of the number
    tiles. phenology.outlook() works out the sentence from the biofix, the
    DD so far and this week's DD rate; milestones gain short names.
    The trap page gets a timing panel with every milestone, a clearer
    biofix block (Confirm, Change the date, Use the catches again), and
    "New liner" as a step that asks which lure went in. The review queue
    asks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

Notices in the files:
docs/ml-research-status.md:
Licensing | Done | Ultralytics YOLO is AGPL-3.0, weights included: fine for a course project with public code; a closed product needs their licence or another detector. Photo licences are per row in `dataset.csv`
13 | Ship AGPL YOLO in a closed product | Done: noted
